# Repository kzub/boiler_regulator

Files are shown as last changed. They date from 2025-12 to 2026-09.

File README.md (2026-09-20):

# Arduino ESBE VRG131 Valve  Motor Controller

A custom firmware implementation for controlling stepper motors using an **Arduino Uno** and **CNC Shield V3**

## 🔧 Hardware Setup

* **Controller:** Arduino Uno + CNC Shield V3.
* **Drivers:** A4988 / DRV8825 (verified with active-low logic).
* **Motors:** NEMA 17 Stepper Motors.
* **Interface:** Rotary Encoder (KY-040 type) with Push Button.
* **Power:** 12V/24V external power supply for shield.

## 🚀 Key Features

* **Independent A-Axis:** Configured the 'A' slot on the CNC shield as an independent axis (Pins 12/13) by removing hardware clone jumpers.
* **Smart Power Management:** Implements "Auto-Enable" logic; drivers hold torque only during movement or menu interaction, and disable (idle) to reduce heat when inactive.
* **Debounced Interface:**
* **Hardware:** None
* **Software:** Non-blocking `millis()` based debounce logic for the button and Interrupt-based handling for the encoder.

## 🛠 Configuration Notes

* **Jumper Settings:** Remove **EN/GND** jumper cap from shield to allow software control of motor enable. Remove **X/Y/Z Clone** jumpers to isolate the A-axis.
* **Jumper Settings:** Install **A12** jumpers to control A axis
* **Pinout:**
* **Z-Axis:** Step (4), Dir (7)
* **A-Axis:** Step (12), Dir (13)
* **Global Enable:** Pin 8 (Active LOW)
* **Encoder:** Pin A2 & A3
* **Button:** Pin A1
* **Endsotps** Pins D11 and D9
* **Temperature sensors** Pin A0

## 📦 Dependencies (PlatformIO)

This project uses the following libraries:

* `waspinator/AccelStepper` (Motor control)
* `paulstoffregen/Encoder` (High-performance encoder reading)

---

### 📝 To-Do / Known Issues

* Ensure the driver Vref is calibrated to match motor current limits.
* If using Pin 12, ensure no SPI conflict if adding displays/SD cards later.
* **Counter constants are not travel:** `triggerBackoff()` normalises the counter to `BACKOFF_STEPS` at one end-stop and `MAX_POSITION_LIMIT - BACKOFF_STEPS` at the other, so the `9000` steps between those constants are a firmware convention and not the real valve travel (roughly `6000` steps). The webapp measures the travel during calibration instead of trusting that range; percentages built from the constants alone open a valve by about one and a half times the requested amount.
* **TODO — Motor 1 reversed endstops:** `motor1.setPinsInverted(true, false, false)` reverses the physical direction, but `manageMotors()` still associates negative motion with `PIN_COMMON_MIN` and positive motion with `PIN_COMMON_MAX`. On the installed controller Motor 1 therefore normalises `min` near `9500` and `max` near `500`, and intermediate travel leaves that range. The webapp handles this by anchoring on whichever constant it last saw, so it needs no separate switch; after fixing the firmware, just recalibrate.

---

### ⚙️ 3D Models (FreeCAD) to print CASE and mount parts included
#### All parts together

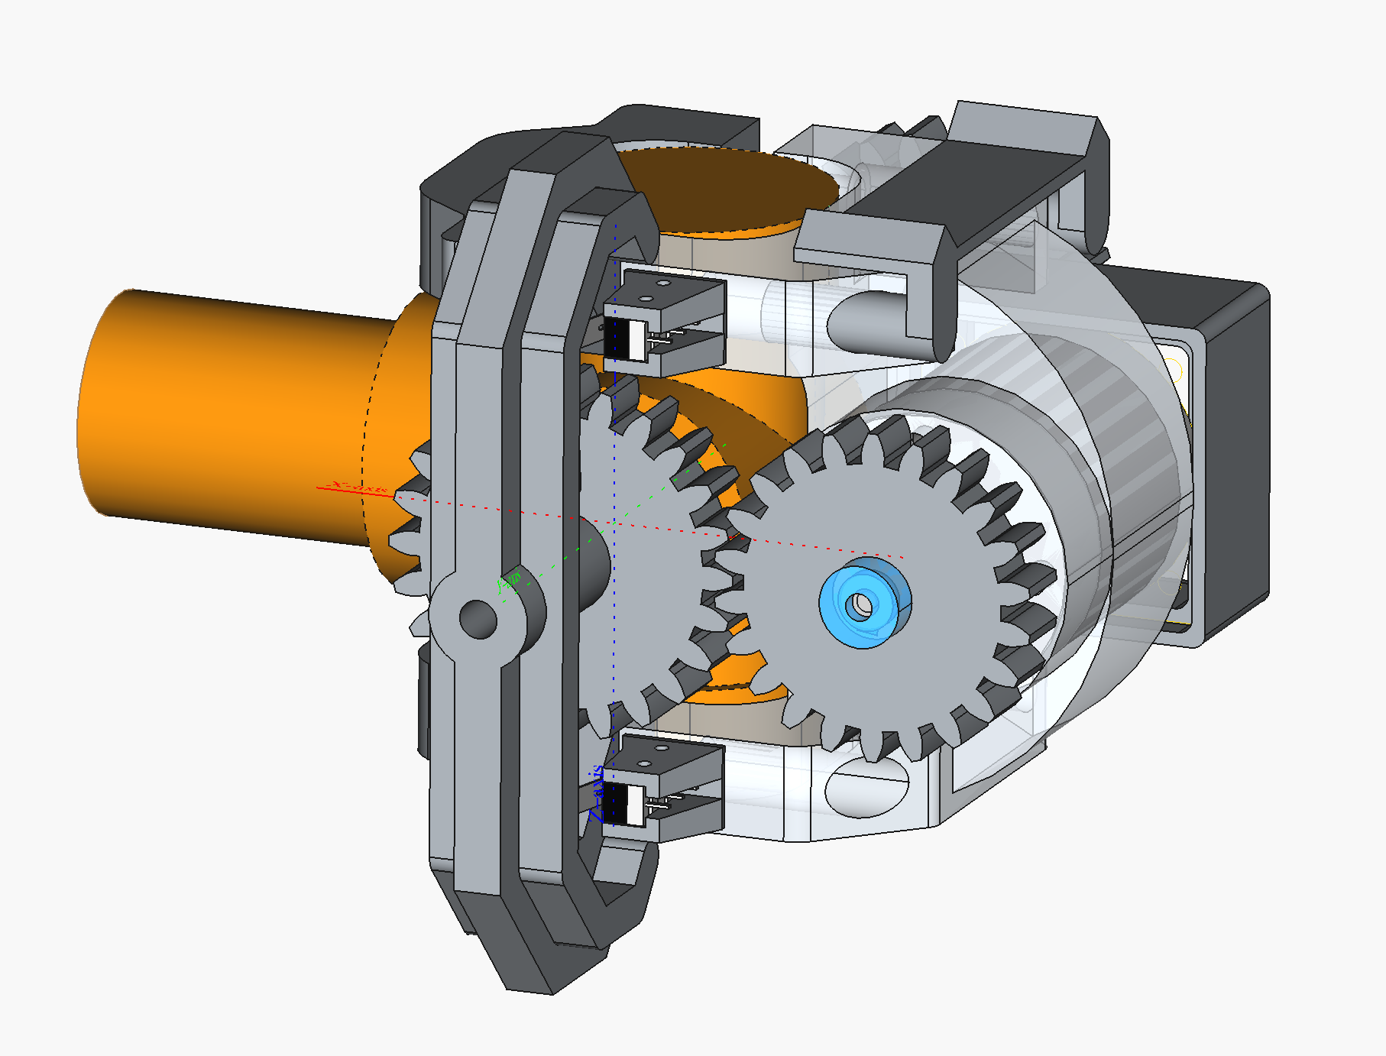
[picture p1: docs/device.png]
Device
 

#### Case

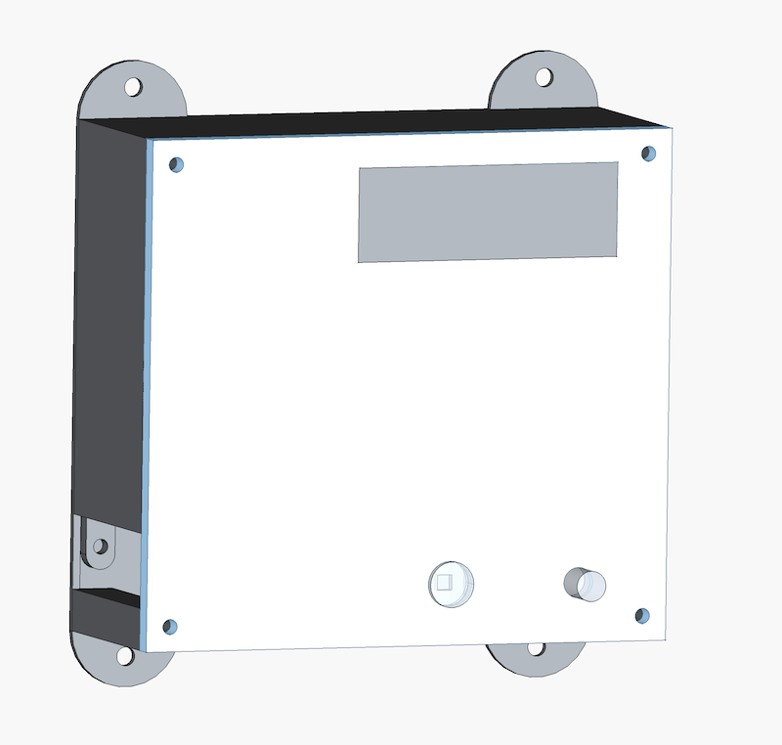
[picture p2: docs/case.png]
Case
 

 #### Real photo
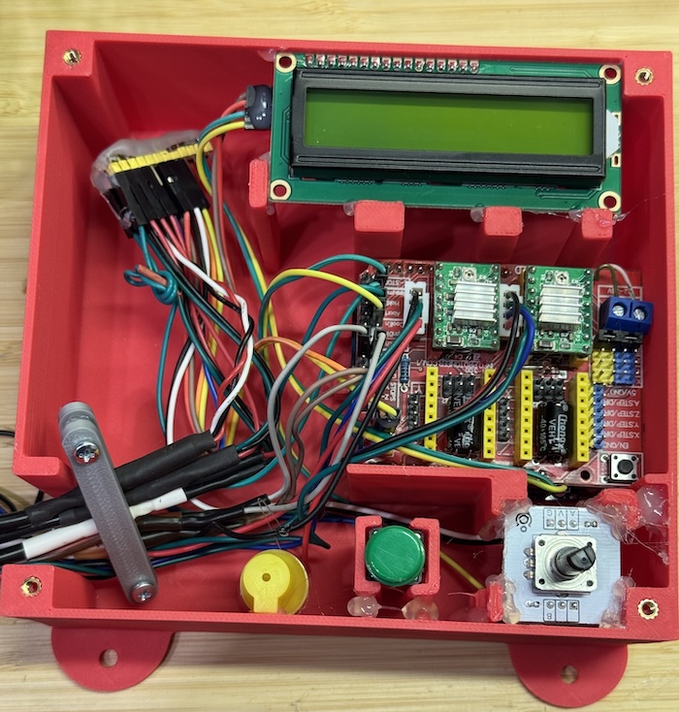
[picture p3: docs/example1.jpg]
 
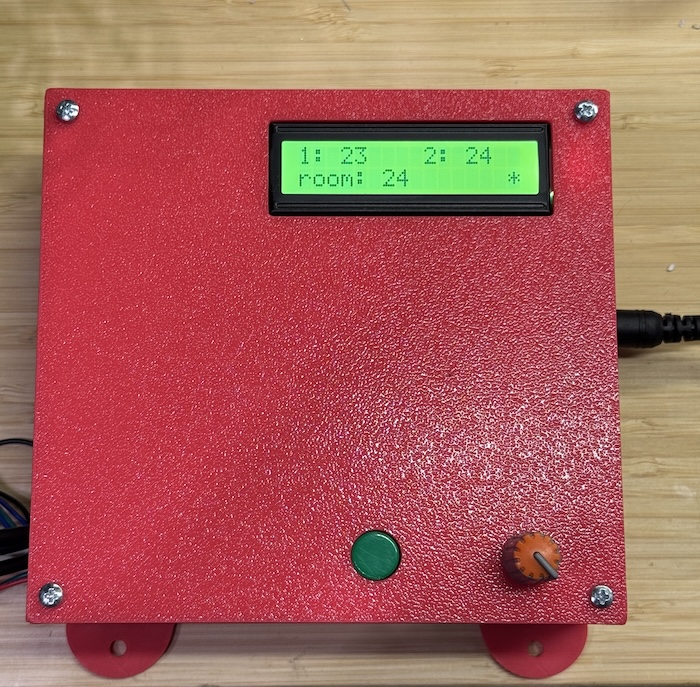
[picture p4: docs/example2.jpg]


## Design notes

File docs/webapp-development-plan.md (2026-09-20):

# План разработки Docker web-приложения для Boiler Regulator

Статус: **готов для передачи другой модели; выбран дизайн A «Домашняя панель»**.
Тема по умолчанию — auto, если владелец не задаст другую.

## 1. Цель

Создать мобильное web-приложение, запускаемое одним Docker Compose сервисом в
домашней сети. Приложение получает состояние Arduino Leonardo ETH, показывает
четыре температуры, калибрует логическую шкалу клапанов и позволяет отправить
первый или второй клапан к физическому пределу `MIN`/`MAX` либо установить
произвольное открытие от 0 до 100%.

Первый релиз должен быть простым, надёжным и безопасным от случайных повторных
команд. После перезапуска Arduino прежняя абсолютная шкала считается
недействительной и backend заново выполняет калибровку. История температур,
расписания, автоматическое регулирование и удалённый доступ через интернет не
входят в MVP.

## 2. Что уже есть в прошивке

Источник: `controller/src/main.cpp`.

### 2.1 Чтение состояния

`GET http://<controller-ip>/status`

Текущий ответ:

```json
{
  "fl1": 21.5,
  "fl2": 22.0,
  "boiler": 24.5,
  "room": 61.0,
  "m1": 100,
  "m2": 9900
}
```

Рабочее отображение для MVP, которое нужно подтвердить на реальном устройстве:

| Поле Arduino | Подпись в приложении |
| --- | --- |
| `fl1` | Первый этаж |
| `fl2` | Второй этаж |
| `boiler` | Температура воды котла |
| `room` | Бойлерная комната |
| `m1` | Позиция регулятора первого этажа |
| `m2` | Позиция регулятора второго этажа |

Не переименовывать поля прошивки в рамках первой версии web-приложения без
отдельного решения: flash ATmega32U4 почти заполнен. Человеческие имена следует
назначить на сервере web-приложения.

### 2.2 Управление

```text
GET /set?motor=1&pos=min
GET /set?motor=1&pos=max
GET /set?motor=2&pos=min
GET /set?motor=2&pos=max
```

Успешный ответ прошивки: `{"status":"ok"}`. Команда означает начало движения,
а не подтверждение достижения концевика. Прошивка также поддерживает
относительное движение. Backend использует его внутри для установки процента,
но не публикует клиенту сырые шаги.

### 2.3 Ограничения текущего API

- нет CORS, поэтому прямые запросы из страницы другого origin ненадёжны;
- все ответы имеют HTTP 200, включая ошибки разбора;
- нет версии API, метки времени, состояния online/busy/moving или результата
  достижения концевика;
- позиция мотора живёт в RAM и после перезапуска контроллера не обязательно
  отражает физическое положение до срабатывания концевика;
- температура читается по индексу OneWire; физическая привязка датчиков не
  закреплена ROM-адресами;
- специальное значение DS18B20 `-127°C` и другие невозможные значения API не
  маркирует как ошибку;
- команды изменения реализованы через GET и не имеют аутентификации;
- при занятости обоих моторов прошивка фактически обслуживает движение первого,
  затем второго, потому что в `manageMotors()` используется `else if`.

Эти ограничения должны быть обработаны прокси и UI, а не скрыты.

### 2.4 Важное свойство текущей шкалы

При достижении концевика прошивка сама переназначает логическую позицию:

- после `MIN` — `BACKOFF_STEPS`, сейчас это `100`;
- после `MAX` — `MAX_POSITION_LIMIT - BACKOFF_STEPS`, сейчас это `9900`.

То есть backend не измеряет реальное число физических шагов между концевиками:
прошивка нормализует счётчик в известный логический диапазон. Калибровка backend
на практике является homing-процедурой: довести клапан до обоих концевиков,
прочитать подтверждённые логические границы и только после этого разрешить
процентное управление. Нельзя hardcode `100/9900`: читать фактические значения
после каждого конца нужно для проверки успешности и совместимости с будущими
версиями прошивки.

### 2.5 Решение для MVP без изменения прошивки

MVP не меняет Arduino firmware. Backend ориентируется только на `m1` и `m2` из
существующего `/status`:

- изменение позиции между poll-запросами означает, что логический счётчик мотора
  движется;
- несколько одинаковых значений подряд после команды означают предполагаемое
  окончание движения;
- значение вне откалиброванного диапазона, прежде всего `0` после reset Arduino,
  инвалидирует шкалу и запускает повторную калибровку;
- изменение позиции без активной backend-команды считается локальным/внешним
  управлением. Если значение остаётся внутри шкалы, backend принимает новую
  позицию и пересчитывает процент.

Backend хранит `lastObservedRaw` и ожидаемую цель. Расхождение с целью само по
себе не всегда означает потерю калибровки: штатный энкодер контроллера также
может изменить позицию. Причиной invalidation являются выход за границы шкалы,
характерный reset в `0`, невозможный скачок или неуспех контрольного движения.

Критическое аппаратное ограничение: `currentPosition()` — программный счётчик
отправленных шагов, а не датчик положения вала. Если физически провернуть вал или
клапан руками без шагов от Arduino, `m1/m2` не изменятся и backend не сможет это
обнаружить. Под «покрутить руками» в поддерживаемом сценарии понимается вращение
штатного энкодера UI, которое запускает мотор и меняет счётчик. Для обнаружения
чисто механического смещения понадобился бы отдельный датчик положения либо
периодическая/ручная повторная homing-калибровка.

## 3. Предлагаемая архитектура

```mermaid
flowchart LR
    P[Мобильный браузер / PWA] -->|HTTPS или HTTP в LAN| W[Docker web service]
    W -->|/api/*| B[Backend proxy]
    B -->|HTTP, короткий timeout| A[Arduino Leonardo ETH]
    B --> C[Calibration manager + command queue]
    C --> D[(Persisted state /data)]
    W --> S[Статические frontend-файлы]
```

### 3.1 Почему нужен backend proxy

Прокси находится в том же origin, что и страница, и решает сразу несколько
задач: обходит отсутствие CORS на Arduino, скрывает адрес устройства от
frontend-кода, нормализует ошибки, вводит timeout, валидирует команды и даёт
возможность позднее добавить авторизацию без изменения прошивки.

Backend также является единственным владельцем очереди движения и состояния
калибровки. Browser polling не должен сам определять границы, вычислять шаги или
отправлять сырой relative move.

### 3.2 Рекомендуемый стек

Для реализации рекомендуется:

- frontend: React + TypeScript + Vite;
- стили: обычный CSS с небольшим набором design tokens, без тяжёлого UI-kit;
- backend: Node.js + TypeScript + Fastify либо минимальный HTTP server;
- runtime: один production-контейнер, который обслуживает собранную статику и
  `/api`; multi-stage Docker build;
- тесты: Vitest для unit/component, Testing Library для UI, Playwright для одного
  критического mobile flow;
- форматирование/проверки: ESLint + TypeScript strict mode.

Допустимая более компактная альтернатива — Preact вместо React. Другой модели не
следует менять стек без причины: важнее простой единый контейнер и предсказуемая
поддержка, чем минимальный размер bundle любой ценой.

### 3.3 Предлагаемая структура папки `webapp`

```text
webapp/
├── src/
│   ├── client/
│   │   ├── api/
│   │   ├── components/
│   │   ├── hooks/
│   │   ├── styles/
│   │   ├── App.tsx
│   │   └── main.tsx
│   ├── server/
│   │   ├── arduino-client.ts
│   │   ├── calibration-manager.ts
│   │   ├── calibration-store.ts
│   │   ├── command-queue.ts
│   │   ├── config.ts
│   │   ├── routes.ts
│   │   └── server.ts
│   └── shared/
│       └── contracts.ts
├── tests/
│   ├── unit/
│   ├── component/
│   └── e2e/
├── public/
├── .dockerignore
├── .env.example
├── Dockerfile
├── compose.yaml
├── package.json
├── tsconfig.json
└── README.md
```

Не создавать отдельные frontend/backend контейнеры для MVP: это усложнит
развёртывание без практической пользы.

### 3.4 Хранение состояния калибровки

Хранить небольшой versioned JSON в `/data/calibration.json`, записывая его
атомарно через временный файл и rename. Для двух регуляторов база данных не
нужна. `/data` должен быть Docker volume, иначе перезапуск web-контейнера будет
запускать лишнюю полную калибровку.

Минимальная persisted schema:

```json
{
  "schemaVersion": 1,
  "regulators": {
    "1": {
      "minRaw": 100,
      "maxRaw": 9900,
      "lastObservedRaw": 4510,
      "lastDesiredPercent": 45,
      "calibratedAt": "2026-09-13T10:00:00.000Z"
    },
    "2": {
      "minRaw": 100,
      "maxRaw": 9900,
      "lastObservedRaw": 5980,
      "lastDesiredPercent": 60,
      "calibratedAt": "2026-09-13T10:02:00.000Z"
    }
  }
}
```

`lastDesiredPercent` не является доказательством текущего физического положения.
Он нужен только как возможная цель восстановления после новой калибровки, если
владелец выберет такой режим. Текущий процент всегда вычисляется из свежего raw
position контроллера. `lastObservedRaw` нужен для определения расхождений при
следующем poll/start, но не заменяет физический датчик положения.

Не перезаписывать файл на каждом poll. Обновлять persisted `lastObservedRaw`
после стабилизации движения, завершения внешнего изменения или с debounce;
калибровочные границы записывать только после полной успешной калибровки.

## 4. Внутренний API Docker-приложения

Браузер работает только с этим API. Адрес Arduino не передаётся клиенту.

### 4.1 `GET /api/status`

Нормализованный успешный ответ:

```json
{
  "temperatures": {
    "floor1": 21.5,
    "floor2": 22.0,
    "boilerWater": 24.5,
    "boilerRoom": 61.0
  },
  "regulators": {
    "floor1": {
      "position": 4216,
      "percent": 42,
      "targetPercent": null,
      "state": "ready"
    },
    "floor2": {
      "position": 9900,
      "percent": 100,
      "targetPercent": null,
      "state": "ready"
    }
  },
  "controller": { "online": true },
  "calibration": { "state": "ready", "progressPercent": 100 },
  "receivedAt": "2026-09-13T10:30:00.000Z"
}
```

Правила proxy:

- timeout запроса к Arduino: начать с 2000 ms, вынести в env;
- проверять `Content-Type` снисходительно, так как прошивка минималистична, но
  строго проверять JSON и наличие нужных числовых полей;
- значения `-127`, `85` при старте датчика, `NaN`, infinity и заведомо выходящие
  за разумный диапазон не показывать как валидную температуру; возвращать `null`
  и диагностический массив `warnings`;
- при недоступности Arduino возвращать `503` с коротким стабильным кодом ошибки,
  не раскрывая stack trace;
- `receivedAt` создаётся proxy только после успешного ответа устройства;
- при позиции вне сохранённой шкалы немедленно вернуть `percent: null` и
  поставить автоматическую калибровку в очередь;
- если после старта оба счётчика равны `0`, считать это reset Arduino и
  инвалидировать обе шкалы;
- если только один счётчик равен `0`/вышел из диапазона, инвалидировать обе шкалы:
  концевики общие, а полная последовательная калибровка дешевле и понятнее
  частично доверенного состояния;
- не кешировать HTTP-ответ браузера (`Cache-Control: no-store`).

### 4.2 `POST /api/regulators/:id/limit`

Тело запроса:

```json
{ "limit": "min" }
```

Где `:id` — только `1` или `2`, `limit` — только `min` или `max`. Backend
преобразует валидный запрос в существующий Arduino GET endpoint. Любые другие
значения отклоняются с `400` и не отправляются устройству.

Успешный ответ Docker API должен быть `202 Accepted`, потому что Arduino
подтверждает приём, но не завершение движения:

```json
{
  "accepted": true,
  "regulator": 1,
  "target": "min",
  "acceptedAt": "2026-09-13T10:31:00.000Z"
}
```

Правила управления:

- backend не повторяет управляющий запрос автоматически: retry может привести к
  нежелательной повторной команде;
- одновременно допускается только один выполняющийся HTTP-запрос команды;
- на уровне UI кнопка блокируется сразу после нажатия и до ответа;
- после `202` UI показывает «Команда принята», а не «Клапан установлен»;
- отсутствие в текущей прошивке признака окончания движения нужно честно
  отразить в UI; нельзя имитировать подтверждённый успех таймером;
- proxy логирует только тип команды, номер регулятора, время, результат и
  длительность; не логирует секреты или полные заголовки.

### 4.3 `POST /api/regulators/:id/target`

Тело запроса:

```json
{ "percent": 55 }
```

Требования:

- `percent` — конечное число от 0 до 100 включительно; UI предлагает шаг 5%, но
  API принимает любое целое значение;
- endpoint доступен только в состоянии calibration `ready`, когда обе свежие
  позиции находятся внутри сохранённых шкал;
- backend вычисляет `targetRaw = round(minRaw + percent / 100 *
  (maxRaw - minRaw))`;
- затем читает свежий `currentRaw`, вычисляет `delta = targetRaw - currentRaw` и
  отправляет Arduino существующий relative command `pos=+N` или `pos=-N`;
- если `delta == 0`, команда мотору не отправляется, API отвечает текущим
  состоянием;
- raw target всегда clamp в `[minRaw, maxRaw]`;
- до завершения движения новые команды этому и второму мотору либо отклоняются
  `409 CONTROLLER_BUSY`, либо помещаются в одну явно реализованную очередь. Для
  MVP рекомендуется одна очередь и не более одной pending user command;
- после приёма backend сохраняет `lastDesiredPercent`, но UI различает requested,
  moving и достигнутую по данным позицию;
- по окончании движения проверить, что фактическая позиция находится в заданном
  допуске, например ±1% шкалы. Иначе вернуть/зафиксировать motion error и не
  показывать цель как достигнутую.

Формула обратного преобразования:

```text
percent = clamp(round((currentRaw - minRaw) * 100 / (maxRaw - minRaw)), 0, 100)
```

Деление запрещено, если шкала отсутствует или `maxRaw <= minRaw`.

### 4.4 Calibration API

- `POST /api/calibration` — вручную запустить/повторить полную калибровку;
- `GET /api/calibration` — состояние и прогресс для UI;
- повторный POST во время calibration возвращает `409 CALIBRATION_IN_PROGRESS`;
- manual limit/target commands во время calibration возвращают
  `409 CALIBRATION_IN_PROGRESS`.

Пример состояния:

```json
{
  "state": "running",
  "phase": "motor1_max",
  "progressPercent": 38,
  "startedAt": "2026-09-13T10:00:00.000Z",
  "error": null
}
```

### 4.5 State machine калибровки

Состояния:

```text
uncalibrated
  → motor1_min → motor1_max
  → motor2_min → motor2_max
  → restoring (если выбран режим восстановления)
  → ready

любой рабочий этап → failed
позиция вне шкалы/reset в 0 → uncalibrated → новая calibration
```

Алгоритм каждого этапа:

1. Получить глобальную блокировку движения.
2. Прочитать стартовую позицию и запомнить время/значение наблюдения.
3. Отправить ровно одну limit-команду без retry.
4. Poll status каждые 250–500 ms. После первого изменения считать мотор
   движущимся. Считать этап завершённым после не менее чем 4–6 одинаковых
   значений подряд и общего стабильного интервала не менее 1.5 s.
5. Если начальное и конечное значения совпали (например, клапан уже был у
   концевика), не завершать этап мгновенно: выдержать минимальное окно наблюдения
   2 s и проверить ожидаемую границу/результат следующей фазы.
6. Ограничить этап timeout примерно 30 s: safety move в прошивке составляет до
   20000 шагов при скорости 1000 шагов/с плюс backoff.
7. Прочитать финальную raw position. Для `MIN` сохранить `minRaw`, для `MAX` —
   `maxRaw`.
8. После пары проверить `maxRaw > minRaw` и разумный минимальный span. Не
   продолжать с нулевой или инвертированной шкалой.
9. После успешной калибровки обоих моторов записать единый snapshot атомарно.

Не записывать частично откалиброванную шкалу как `ready`. Калибровка выполняется
строго последовательно из-за общих концевиков. Stability detection не доказывает
механическое движение: оно доказывает только завершение изменения программного
счётчика. Поэтому timeout, проверка конечных границ и возможность ручной
повторной калибровки обязательны.

### 4.6 Поведение при старте и потере питания

При старте backend:

1. Загрузить persisted snapshot.
2. Получить status Arduino.
3. Если snapshot валиден и обе текущие позиции находятся внутри соответствующих
   шкал — принять их как свежие, пересчитать проценты и перейти в `ready` без
   движения.
4. Если snapshot отсутствует/повреждён, позиция равна `0` или находится вне
   шкалы — удалить обе шкалы из памяти, записать `uncalibrated` и запустить
   автоматическую калибровку.
5. Если Arduino недоступен — оставаться `waiting_for_controller`; начать
   calibration после восстановления связи.

При потере связи во время работы не считать это немедленным доказательством
reset. Отключить команды, сохранить последнюю информацию только как stale и
ждать возвращения. После возврата сравнить raw positions со шкалой и последним
наблюдением. Значение `0`/вне диапазона запускает recalibration; новое значение
внутри диапазона принимается как локальное управление и становится текущим.

Эвристика не может доказать каждый reboot. Если контроллер успел перезапуститься,
а затем его штатным энкодером довели до значения внутри старой шкалы до первого
backend poll, reset может остаться незамеченным. Это принятый риск варианта без
изменения firmware; он должен быть указан в README и компенсирован доступной
ручной кнопкой «Перекалибровать».

### 4.7 Матрица расхождений позиции

| Наблюдение | Интерпретация | Действие backend |
| --- | --- | --- |
| Позиция меняется после backend-команды | Мотор движется | Продолжать частый poll, показывать moving |
| Позиция стабильна не менее 1.5 s | Предполагаемая остановка | Сверить с target/limit и снять moving |
| Позиция изменилась без backend-команды, но внутри шкалы | Управление штатным энкодером или другим API-клиентом | Принять raw, пересчитать процент, сбросить устаревший draft target |
| Позиция стабильна внутри шкалы, но не совпала с backend target | Команда не достигла ожидаемой логической цели | Показать warning; не выдавать цель за достигнутую |
| Одна или обе позиции равны `0` после прежней валидной шкалы | Наиболее вероятен reset Arduino | Инвалидировать обе шкалы и запустить calibration |
| Позиция ниже `minRaw` или выше `maxRaw` с допуском | Счётчик/шкала больше не согласованы | Инвалидировать обе шкалы и запустить calibration |
| Arduino не отвечает | Сетевая проблема или отключение питания, причина неизвестна | Показать offline, пока не инвалидировать; проверить позиции после возврата |
| Вал повернули физически, но raw не изменился | Не наблюдается существующим оборудованием | Backend ничего определить не может; нужна ручная calibration |

### 4.8 Служебные endpoints

- `GET /health/live` — процесс запущен, без обращения к Arduino;
- `GET /health/ready` — конфигурация валидна; допустимо возвращать ready даже при
  временно выключенном Arduino, чтобы Docker не перезапускал приложение из-за
  сетевой проблемы устройства.

## 5. Конфигурация и Docker

Минимальные переменные окружения:

```dotenv
CONTROLLER_BASE_URL=http://192.168.88.20
CONTROLLER_TIMEOUT_MS=2000
PORT=8080
STATUS_POLL_INTERVAL_MS=5000
MOTION_POLL_INTERVAL_MS=300
MOTION_TIMEOUT_MS=30000
AUTO_CALIBRATE=true
CALIBRATION_DATA_PATH=/data/calibration.json
```

Требования:

- `CONTROLLER_BASE_URL` обязателен и валидируется при старте;
- URL разрешает только `http:`/`https:`, query и credentials запрещены;
- production image запускается не от root;
- зависимости устанавливаются lockfile-режимом;
- build stage не попадает в runtime image;
- контейнер имеет healthcheck по `/health/live`;
- `compose.yaml` содержит `restart: unless-stopped`, проброс `${WEB_PORT:-8080}:8080`
  и named volume для `/data`;
- адрес Arduino задаётся env, а не hardcode;
- README содержит команды запуска, обновления, просмотра состояния и остановки;
- если приложение будет доступно только в LAN, не заявлять HTTPS. Для удалённого
  доступа нужен отдельный reverse proxy/VPN и решение по авторизации.

## 6. Поведение мобильного интерфейса

### 6.1 Загрузка и обновление

- при открытии сразу запросить `/api/status`;
- затем опрашивать раз в 5 секунд; интервал приходит из build config или остаётся
  фиксированным в клиенте, серверный env не должен случайно обещать клиенту то,
  чего он не использует;
- не запускать новый poll, пока предыдущий не завершён;
- при уходе вкладки в background снизить частоту или остановить polling, при
  возврате обновить сразу;
- показывать «Обновлено N сек. назад»;
- после двух последовательных ошибок показывать заметный offline state и время
  последних достоверных данных;
- при ошибке не обнулять экран и не выдавать старые данные за свежие.

### 6.2 Температуры

- показывать одну цифру после запятой и `°C`;
- для `null` показывать `—` и подпись «нет данных»;
- не окрашивать температуру как «нормальную/опасную» без согласованных порогов;
- подписи должны однозначно различать «Температура воды котла» и «Бойлерная
  комната»;
- числа использовать с tabular figures, чтобы обновление не дёргало layout.

### 6.3 Карточка регулятора и процентное управление

- выбран layout A: две карточки этажей одновременно видны под инженерными
  температурами;
- в `ready` крупно показывать текущий процент, рядом вторично — raw position;
- `−5%`/`+5%` и ползунок меняют локальный draft target, не отправляя движение;
- отдельная кнопка «Установить N%» открывает подтверждение и создаёт ровно одну
  backend-команду;
- ползунок имеет шаг 1%, кнопки — шаг 5%;
- различать `Текущее 42%` и `Цель 55%`, особенно во время движения;
- при `percent: null` не показывать 0%; вместо этого выводить «Шкала не
  откалибрована»;
- во время calibration показывать текущую фазу понятным текстом, общий progress
  и предупреждение, что оба регулятора будут двигаться автоматически;
- при `failed` показать причину и кнопку «Повторить калибровку»;
- управление обеими карточками блокируется во время глобальной калибровки.
- если позиция меняется без команды web-приложения, плавно обновить текущий
  процент и пометить событие как локальное управление без тревожного сообщения;

### 6.4 Команды MIN/MAX

- в каждом блоке явно указать этаж;
- зона нажатия не менее 44 px, расстояние между конфликтующими кнопками;
- подтверждение должно назвать этаж и направление: «Первый этаж → MAX?»;
- пока запрос отправляется, обе кнопки этого регулятора отключены;
- защита от double tap обязательна;
- после ответа показать неблокирующее сообщение «Команда принята»;
- при timeout показать «Не удалось подтвердить приём команды». Не предлагать
  автоматический retry; пользователь может сначала проверить состояние;
- позицию (`m1`/`m2`) показывать как вторичную диагностическую информацию и не
  превращать в проценты, пока текущая позиция не подтверждена откалиброванным
  диапазоном.

### 6.5 Accessibility и mobile details

- корректный viewport и отсутствие горизонтальной прокрутки при 320 px;
- поддержка safe-area inset на iPhone;
- системный шрифт и размер основного текста не меньше 16 px;
- видимый keyboard focus;
- semantic headings/buttons/dialog;
- `aria-live` для статуса обновления и результата команды;
- `prefers-reduced-motion` отключает декоративные переходы;
- светлая и тёмная тема должны иметь достаточный контраст, если выбран режим
  auto.

## 7. Обработка ошибок

Нужны стабильные коды, которые frontend переводит в русские сообщения:

| HTTP | Код | Смысл для UI |
| --- | --- | --- |
| 400 | `INVALID_REQUEST` | Внутренняя ошибка запроса; команда не отправлена |
| 409 | `CONTROLLER_BUSY` | Дождитесь завершения текущего движения |
| 409 | `CALIBRATION_REQUIRED` | Процент недоступен до калибровки |
| 409 | `CALIBRATION_IN_PROGRESS` | Идёт автоматическая калибровка |
| 502 | `INVALID_CONTROLLER_RESPONSE` | Контроллер ответил неожиданно |
| 502 | `CALIBRATION_FAILED` | Концевик/шкала не подтверждены |
| 503 | `CONTROLLER_UNREACHABLE` | Контроллер недоступен |
| 504 | `CONTROLLER_TIMEOUT` | Контроллер не ответил вовремя |

Логи сервера должны позволять отличить DNS/connect/timeout/invalid JSON, но API
не должен возвращать внутренние адреса и stack traces пользователю.

## 8. Тестовая стратегия

Для разработки создать mock Arduino server с тем же минимальным контрактом. Это
позволит другой модели и CI работать без физического контроллера.

Обязательные unit-тесты:

- преобразование Arduino status в публичный контракт;
- валидация четырёх температур и двух позиций;
- позиция `0`/вне диапазона немедленно инвалидирует обе шкалы;
- повторный backend start с позициями внутри шкал не запускает движения;
- первый start без snapshot запускает calibration;
- внешнее изменение внутри шкалы обновляет процент без recalibration;
- изменение позиции определяется по последовательности status samples;
- окончание движения определяется только после заданного stable window;
- state machine проходит четыре limit-фазы строго последовательно;
- timeout/ошибка любой фазы не сохраняет частичную шкалу как ready;
- валидация `minRaw < maxRaw` и минимального span;
- формулы raw↔percent, clamp, rounding и границы 0/100%;
- атомарная запись и восстановление calibration JSON;
- target percent преобразуется ровно в одну relative Arduino command;
- маппинг регулятора и `min/max` в Arduino URL;
- timeout, invalid JSON, отсутствующее поле, сетевой отказ;
- запрет неизвестного motor/limit;
- отсутствие автоматического retry управляющей команды.

Обязательные component/UI-тесты:

- initial loading → актуальные данные;
- offline state сохраняет последние значения и помечает их устаревшими;
- `null` температура отображается как «нет данных»;
- подтверждение содержит правильный этаж и предел;
- draft target меняется кнопками/ползунком без сетевой команды;
- нажатие «Установить» отправляет ровно один target request;
- uncalibrated state скрывает процент и блокирует target controls;
- calibration progress и failed state отображаются корректно;
- double tap не создаёт две команды;
- success означает «принята», а не «выполнена»;
- все интерактивные элементы доступны с клавиатуры.

Минимальный Playwright mobile smoke test (например, viewport iPhone 13): открыть
экран после calibration, увидеть четыре температуры и два процента, подготовить
цель 55% для регулятора 1, подтвердить одну команду, дождаться ready state, затем
смоделировать сброс обеих позиций в `0` и увидеть блокировку UI с новой
calibration.

Ручная проверка на реальном устройстве:

1. Сверить каждый из четырёх датчиков с физическим расположением.
2. Выполнить `MIN` и `MAX` для каждого клапана по отдельности.
3. Проверить отображение позиции до, во время и после движения.
4. Проверить цели 5%, 50% и 95% для каждого клапана.
5. Отключить Ethernet Arduino и проверить offline UI без ложной invalidation.
6. Перезапустить Arduino, проверить сброс `m1/m2` в `0`, немедленный сброс
   процентов и автоматическую повторную калибровку.
7. Перезапустить только Docker-контейнер при работающем Arduino и убедиться, что
   persisted шкала используется без движения, если позиции внутри диапазона.
8. Повернуть штатный энкодер контроллера и проверить обновление процента без
   повторной калибровки.
9. Проверить телефон шириной 320–430 px, portrait, светлую и тёмную системную
   тему.

## 9. Этапы разработки и checklist

### Этап 0 — зафиксировать решения

- [x] Владелец выбрал вариант дизайна A «Домашняя панель».
- [ ] Зафиксирована тема: light/dark/auto.
- [ ] На физическом устройстве подтверждён mapping четырёх датчиков.
- [ ] Подтверждено значение `MIN`/`MAX` для каждого клапана; до этого UI не
      использует слова «открыть/закрыть».
- [ ] Подтверждено, что приложение остаётся только в доверенной LAN, либо создана
      отдельная задача на authentication/TLS.
- [ ] Выбрано положение после автокалибровки: предыдущая цель, `MIN` или `MAX`.

### Этап 1 — проверить поведение существующей firmware

- [ ] Не изменять `controller/src/main.cpp`.
- [ ] Замерить изменение `m1/m2` во время движения с poll 250/300/500 ms.
- [ ] Подтвердить, что `/status` отвечает во время обычного движения мотора.
- [ ] Замерить время, после которого позиция стабилизируется у обоих концевиков.
- [ ] Подтвердить реальные финальные позиции после `MIN` и `MAX` для каждого
      мотора.
- [ ] Выполнить reset/power cycle и подтвердить, что оба счётчика становятся `0`.
- [ ] Повернуть штатный энкодер и подтвердить, что соответствующее `m1/m2`
      изменяется.
- [ ] Отдельно зафиксировать, что физический поворот вала без работы мотора не
      отражается в `/status`.

Критерий завершения: измерены poll/stability параметры и подтверждены наблюдаемые
признаки движения/reset, на которых будет основан backend.

### Этап 2 — scaffold и контракты

- [ ] Создать frontend/server TypeScript project внутри `webapp`.
- [ ] Добавить lockfile, strict TypeScript, lint, test и build scripts.
- [ ] Описать shared types публичного API.
- [ ] Добавить `.env.example`, не коммитить реальный секретный env.
- [ ] Создать mock Arduino server и фикстуры good/invalid/offline.
- [ ] Mock должен симулировать изменение/стабилизацию позиции, reset в `0`,
      локальное управление, концевики и calibration failure.
- [ ] Обновить `webapp/README.md` точными командами разработки.

Критерий завершения: чистая установка зависимостей, lint, typecheck и пустой
production build выполняются одной документированной последовательностью.

### Этап 3 — backend proxy и calibration manager

- [ ] Реализовать и протестировать config validation.
- [ ] Реализовать Arduino client с `AbortSignal.timeout` или эквивалентом.
- [ ] Реализовать `GET /api/status` и нормализацию ответа.
- [ ] Реализовать `POST /api/regulators/:id/limit` со строгой validation.
- [ ] Реализовать persisted versioned calibration store в `/data` с atomic write.
- [ ] Реализовать глобальную command queue/lock.
- [ ] Реализовать полную последовательную state machine калибровки.
- [ ] Реализовать comparison с persisted bounds/last observed position и
      invalidation при `0`/выходе из диапазона.
- [ ] Реализовать automatic calibration после первого запуска/reset heuristic.
- [ ] Реализовать `GET/POST /api/calibration`.
- [ ] Реализовать raw↔percent и `POST /api/regulators/:id/target`.
- [ ] Реализовать motion detection по изменению raw position.
- [ ] Реализовать completion по stable sample window, target tolerance и timeout.
- [ ] Реализовать обработку локального движения внутри шкалы без invalidation.
- [ ] Убедиться, что command request не имеет retry.
- [ ] Добавить `/health/live` и `/health/ready`.
- [ ] Добавить structured logging без утечки внутренних деталей в API.
- [ ] Добавить graceful shutdown.

Критерий завершения: backend проходит unit/integration тесты против mock Arduino,
включая полный calibration flow, reset в `0`, внешнее движение, target 0–100%,
timeout и malformed JSON. Ни один failure path не оставляет ложное состояние
`ready`.

### Этап 4 — базовый mobile UI

- [ ] Реализовать выбранную компоновку A «Домашняя панель».
- [ ] Создать компоненты TemperatureMetric, RegulatorControl, ConnectionStatus,
      CommandConfirm и Toast/InlineNotice.
- [ ] Реализовать initial load, polling без пересечений и visibility handling.
- [ ] Реализовать fresh/stale/offline states.
- [ ] Реализовать форматирование температур и missing sensor state.
- [ ] Показывать позицию только как диагностические шаги.
- [ ] Добавить current/draft/target percent, кнопки ±5%, slider и одну кнопку
      применения.
- [ ] Добавить calibration progress, uncalibrated и failed states.
- [ ] Реализовать подтверждение команды и блокировку double tap.
- [ ] Различить accepted, timeout и rejected сообщения.
- [ ] Проверить 320/360/390/430 px без горизонтального overflow.

Критерий завершения: все четыре температуры, текущие проценты, постепенная
установка и четыре limit-действия доступны на телефоне. UI никогда не вычисляет
процент из позиции вне шкалы и не заявляет о достижении цели без стабильных
данных контроллера.

### Этап 5 — дизайн, доступность и устойчивость

- [ ] Применить выбранные цвета, typography, spacing и состояния.
- [ ] Добавить auto theme, если она выбрана.
- [ ] Проверить контраст, focus, screen reader names и reduced motion.
- [ ] Добавить safe-area padding.
- [x] Добавить Error Boundary и понятный фатальный экран.
- [ ] Добавить component tests и mobile Playwright smoke test.
- [ ] Проверить отсутствие layout shift при обновлении чисел.
- [x] Ограничен retention диагностического журнала: backend хранит 500 последних
      записей (`defaultJournalLimit`), browser — 200 (`browserLogLimit`) в
      `sessionStorage` с уменьшением сохранённой копии при отказе quota;
      обрезание покрыто unit-тестами.

Критерий завершения: выбранный дизайн соответствует макету, основные сценарии
проходят мышью, touch и клавиатурой.

### Этап 6 — Docker и эксплуатационная документация

- [ ] Создать multi-stage Dockerfile и `.dockerignore`.
- [ ] Запустить runtime от non-root пользователя.
- [ ] Добавить `compose.yaml`, healthcheck и restart policy.
- [ ] Добавить named volume для `/data/calibration.json`.
- [ ] Проверить конфигурацию с IP реального Arduino.
- [ ] Проверить image на отсутствие devDependencies/build sources, где возможно.
- [ ] Документировать start/update/logs/stop/backup config.
- [ ] Добавить раздел troubleshooting: timeout, wrong IP, invalid sensor,
      controller reboot.

Критерий завершения: на чистой машине с Docker приложение запускается одной
командой и открывается с телефона в той же LAN.

### Этап 7 — приёмка на устройстве

- [ ] Выполнить ручной hardware checklist из раздела 8.
- [ ] Проверить минимум 30 минут polling без роста памяти и каскада запросов.
- [ ] Проверить восстановление после перезапуска web-контейнера.
- [ ] Проверить восстановление после потери/возврата Arduino в сети.
- [ ] Проверить защиту от повторного нажатия на реальном touch-устройстве.
- [ ] Проверить полный power-cycle Arduino с автоматической invalidation и
      calibration.
- [ ] Проверить, что restart только web-контейнера не двигает клапаны повторно.
- [ ] Зафиксировать фактический mapping датчиков в README.
- [ ] Зафиксировать URL приложения и параметры compose для домашнего сервера.

Критерий завершения MVP: приложение устойчиво показывает четыре корректно
подписанные температуры, откалиброванные проценты двух клапанов, принимает
только разрешённые limit/percent команды, сбрасывает шкалу при наблюдаемом reset
позиции, честно показывает состояние связи и разворачивается через Docker по
инструкции.

## 10. Опциональный этап после MVP

Не включать эти пункты в первую реализацию без отдельного запроса:

- PWA manifest, иконки и offline application shell;
- история температур и графики (потребуют хранилища);
- автоматический режим/расписание;
- push-уведомления;
- authentication и remote access;
- изменение IP Arduino из web UI;
- возможное будущее обновление прошивки для ROM-address датчиков, boot/session
  id, command id и подтверждённого результата достижения механической цели.

## 11. Правила для модели-исполнителя

1. Не изменять `controller/src/main.cpp` в рамках web MVP. План намеренно основан
   только на существующих `m1/m2`.
2. Если firmware станет отдельной задачей, соблюдать `AGENTS.md`: никаких Arduino
   `String`, статические строки через `F()`, никаких тяжёлых библиотек,
   обязательно `pio run` и отчёт по Flash/RAM.
3. Не угадывать физическую семантику датчиков и направления клапана; использовать
   подтверждённый mapping.
4. Не добавлять автоматический retry для управляющих команд.
5. Не сообщать пользователю «достигнут MIN/MAX», пока API не умеет это
   подтверждать.
6. Не публиковать порт приложения в интернет без отдельного security решения.
7. Делать каждый этап небольшим проверяемым изменением и отмечать checklist только
   после теста соответствующего критерия завершения.
8. Не утверждать, что backend обнаруживает физический ручной поворот вала: без
   датчика обратной связи это технически невозможно.

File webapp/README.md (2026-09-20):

# Boiler Regulator Web App

Mobile-first панель для контроллера клапанов. Выбран дизайн A «Домашняя панель»;
тема следует системной (auto). Приложение не меняет прошивку Arduino.

## Запуск в Docker

На домашнем сервере создайте `.env` из примера и укажите IP Arduino:

```sh
cp .env.example .env
# отредактируйте CONTROLLER_BASE_URL в .env
docker compose up -d --build
```

Панель будет доступна по `http://<адрес-сервера>:8080`. Она рассчитана только на
доверенную LAN. Не публикуйте этот порт в интернет без отдельного reverse proxy,
TLS и аутентификации.

Полезные команды:

```sh
docker compose logs -f
docker compose pull && docker compose up -d --build
docker compose down
```

Калибровка и последний наблюдавшийся процент открытия сохраняются в named volume
`calibration-data`; его не следует удалять при обычном обновлении. Для резервной
копии можно сохранить содержимое `/data/calibration.json` из контейнера. Если
Arduino перезапустится и вернёт `0` или позицию вне сохранённой шкалы, сервер
пометит шкалу недействительной. При следующей калибровке он измерит MIN/MAX и
вернёт оба регулятора к последним сохранённым процентам открытия. Автоматический
запуск этой процедуры зависит от `AUTO_CALIBRATE`.

На концевике прошивка не измеряет положение, а записывает в счётчик константу:
`500` на одном конце и `9500` на другом. Между ними 9000 шагов, тогда как клапан
проходит около 6000, поэтому шкала «от константы до константы» открывала клапан
примерно в полтора раза сильнее запрошенного (50% превращались в ~75%). Backend
измеряет фактический ход во время калибровки и считает проценты по нему.

Калибровка каждого регулятора — ровно два прохода: MIN, затем MAX (он же измеряет
ход), после чего одна относительная команда возвращает прежнее открытие. Третий
проход MIN больше не нужен. У первого мотора после инверсии DIR константы
записываются наоборот (`min` → `9500`, `max` → `500`), и его счётчик во время
работы выходит за обе константы — backend опирается на последнюю записанную
константу и считает шаги от неё, отдельного переключателя для этого нет.

Формат сохранённой калибровки — schema 4. Файлы прежних версий не читаются: в них
не было измеренного хода. После обновления панель попросит перекалибровку и до
неё клапаны не двигает.

## Развёртывание на NAS (bob)

Контейнер на Synology создаётся через Container Manager. Подготовленный compose,
скрипт синхронизации исходников и пошаговая инструкция лежат в
[`../deploy/bob/`](../deploy/bob/README.md). Панель там слушает порт **8088**
(8080 на bob занят vaultwarden), калибровочные данные хранятся в
`/volume1/docker/dacha-temp/data`, а `AUTO_CALIBRATE` выключен, чтобы
перезапуск контейнера не двигал клапаны сам по себе.

Обновление одной командой — `./deploy/bob/deploy.sh`: копирует исходники,
пересобирает образ, перезапускает контейнер и проверяет, что отвечает уже новая
сборка. Просто «Start» в Container Manager без «Build» оставляет старый образ,
поэтому внизу страницы показаны версия, коммит и время сборки, а
`curl -s http://bob:8088/api/version` отвечает на тот же вопрос из терминала.

## Локальная разработка

Требуется Node.js 22+.

```sh
npm ci
cp .env.example .env
npm run dev
```

В отдельной консоли доступны проверки:

```sh
npm run lint
npm run typecheck
npm test
npm run build
```

Адрес Arduino остаётся только в серверной конфигурации: браузер обращается к
`/api`, поэтому CORS прошивки не используется. Команды MIN/MAX и процентные
команды подтверждают лишь приём, а не достижение механической позиции. Сервер не
повторяет их автоматически.

Backend не выполняет фонового polling Arduino в idle-режиме. Обычный запрос
`/status` приходит от открытой панели раз в 5 секунд, а во время движения — раз
в 300 ms. Явно запущенная калибровка является исключением: ей нужен временный
частый polling для безопасного завершения этапов. Изменения счётчиков, сделанные
штатным энкодером контроллера, сохраняются как новое последнее положение.

## Диагностика

- «Нет связи» — проверьте IP, питание и доступность Arduino из Docker-сети.
- «Шкала не откалибрована» — дождитесь автоматической процедуры или нажмите
  «Перекалибровать».
- Значение `—` у температуры означает недостоверный ответ датчика (`-127°C`,
  стартовые `85°C` и физически невозможные величины скрываются).
- Поворот вала вручную без запуска мотора нельзя обнаружить текущим
  оборудованием. После него выполните ручную перекалибровку.

Подтверждённый mapping датчиков: `fl1` — первый этаж, `fl2` — второй этаж,
`boiler` — температура воды котла, `room` — бойлерная комната. Смысл MIN/MAX
следует подтверждать по чек-листу в плане.

Project documentation:

- [Design options](../docs/webapp-design-options.md) — mobile UI concepts and selection criteria.
- [Development plan](../docs/webapp-development-plan.md) — architecture, API contract, delivery phases, acceptance criteria, and implementation checklist.

The current Arduino firmware remains in `../controller` and is not modified by
the web application work unless a plan item explicitly calls for a separate,
size-checked firmware change.

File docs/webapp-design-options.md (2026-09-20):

# Варианты дизайна мобильного приложения регулятора

Статус документа: **выбран вариант A «Домашняя панель»**.

## 1. Общие требования ко всем вариантам

Приложение проектируется прежде всего для телефона шириной от 320 px и должно
нормально работать как в мобильном браузере, так и после добавления на домашний
экран. Главный экран содержит только то, что нужно для ежедневного контроля:

- температуру первого этажа;
- температуру второго этажа;
- температуру в бойлерной комнате;
- температуру входящей воды от котла;
- отдельное управление первым и вторым регулятором командами `MIN` и `MAX`;
- отображение текущего открытия в процентах после успешной калибровки;
- постепенную установку открытия с шагом 5% и выбор произвольной цели ползунком;
- состояние связи с контроллером и время последнего успешного обновления;
- понятную индикацию отправки команды, успеха и ошибки.

Общие принципы:

- крупные зоны нажатия не менее 44×44 px;
- значения температуры читаются без приближения экрана;
- кнопки двух этажей визуально и пространственно разделены;
- цвет не является единственным способом различить состояние;
- `MIN` и `MAX` называются именно так, пока не подтверждено, что они однозначно
  соответствуют «закрыть» и «открыть» для обеих физических установок;
- потенциально случайная команда подтверждается повторным действием или
  коротким диалогом;
- интерфейс показывает недостоверное/устаревшее значение явно, а не оставляет
  старую температуру выглядеть как актуальную.

## 2. Выбранный вариант A — «Домашняя панель»

Спокойный светлый интерфейс. Сверху — компактный статус связи и две инженерные
температуры, ниже — две большие карточки этажей. В каждой карточке крупно
показана температура этажа и рядом находятся две широкие кнопки `MIN`/`MAX`.
После калибровки карточка также показывает процент открытия и даёт постепенно
изменить целевое значение.

Предлагаемая модель управления процентом:

- крупное текущее значение, например «Открыто 42%»;
- кнопки `−5%` и `+5%` меняют только подготовленную цель, но не двигают клапан
  при каждом нажатии;
- ползунок позволяет быстро выбрать любое значение от 0 до 100%;
- отдельная кнопка «Установить 55%» отправляет одну команду после подтверждения;
- `MIN` и `MAX` остаются быстрыми действиями и также требуют подтверждения;
- во время калибровки процентные элементы отключены, вместо процента показан
  текущий этап и общий прогресс;
- при утрате калибровки карточка не показывает вычисленный процент и сообщает
  «Требуется калибровка».

Сильные стороны:

- все четыре температуры и оба регулятора видны без переходов;
- удобно быстро сравнивать этажи;
- интерфейс понятен членам семьи без технических знаний;
- хорошо масштабируется, если позднее появятся графики или автоматический режим.

Компромиссы:

- карточки занимают больше вертикального места;
- на очень маленьком экране нижняя часть второй карточки может потребовать
  небольшой прокрутки.

Рекомендуется, если приложение будет обычной домашней панелью и им будут
пользоваться несколько людей.

## 3. Вариант B — «Один этаж в фокусе»

В верхней части находятся четыре компактных показателя температуры. Ниже —
переключатель «1 этаж / 2 этаж», после которого показывается только выбранный
регулятор, его температура, позиция и две очень крупные кнопки `MIN`/`MAX`.

Сильные стороны:

- самые крупные и безопасные органы управления;
- удобно пользоваться одной рукой;
- меньше риск нажать кнопку не того этажа;
- хорошо подходит для узких экранов.

Компромиссы:

- состояние второго регулятора скрыто за переключателем;
- для управления обоими этажами требуется дополнительное действие;
- сравнение этажей менее наглядно.

Рекомендуется, если чаще всего регулируется только один этаж за раз, а защита от
ошибочного нажатия важнее одновременного обзора.

## 4. Вариант C — «Инженерная консоль»

Контрастная тёмная панель высокой плотности. Четыре температуры собраны в сетку,
регуляторы представлены компактными строками с позицией, индикатором движения и
кнопками `MIN`/`MAX`. Служебный статус связи заметнее, чем в остальных вариантах.

Сильные стороны:

- максимум информации помещается на одном экране;
- хорошо читается в тёмном техническом помещении;
- удобно диагностировать связь и состояние устройства;
- естественно расширяется служебными данными.

Компромиссы:

- выглядит более технически;
- плотная компоновка менее дружелюбна для случайного пользователя;
- для солнечного света потребуется тщательно проверить контрастность.

Рекомендуется, если приложением в основном пользуется владелец системы и важна
диагностическая информация.

## 5. Принятое решение

Владелец проекта выбрал **вариант A**. Варианты B и C сохранены выше только как
история рассмотренных решений. Если отдельного решения по теме не будет, следует
использовать автоматическую тему по настройке телефона с качественной светлой
версией по умолчанию.

## 6. Состояния выбранного интерфейса

Карточка регулятора должна иметь четыре взаимоисключающих состояния:

1. `CALIBRATING` — показан этап `MIN`/`MAX`, номер регулятора и общий прогресс;
   ручные команды заблокированы.
2. `READY` — показаны текущий процент, позиция в шагах, выбор цели и действия
   `MIN`/`MAX`.
3. `MOVING` — показаны текущий и целевой проценты; повторные команды этому
   регулятору заблокированы.
4. `UNCALIBRATED/ERROR` — процент скрыт, причина понятна, доступно действие
   «Повторить калибровку».

Калибровка обоих регуляторов выполняется последовательно, потому что концевики
общие. Глобальный статус калибровки располагается над карточками этажей и не
вытесняет четыре температурные метрики.

## 7. Не принятые пока продуктовые решения

Эти вопросы не блокируют выбор визуального варианта, но должны быть закрыты до
финальной приёмки:

1. Подтвердить физическое соответствие `MIN` и `MAX` открытию/закрытию каждого
   клапана.
2. Подтвердить соответствие индексов датчиков полям `fl1`, `fl2`, `boiler`,
   `room`. Текущая прошивка использует порядок обнаружения OneWire, а не адреса
   датчиков, поэтому порядок может оказаться нестабильным после замены датчика.
3. Решить, требуется ли авторизация в домашней сети. Базовый план исходит из
   доверенной локальной сети и не публикует приложение в интернет.
4. Решить, нужна ли установка как PWA. В плане это вынесено в отдельный этап и
   не требуется для первого рабочего релиза.
5. Выбрать положение клапанов после автоматической калибровки: восстановить
   последние целевые проценты, перейти в `MIN` или остаться в `MAX`. Реализация
   не должна молча выбирать это поведение.

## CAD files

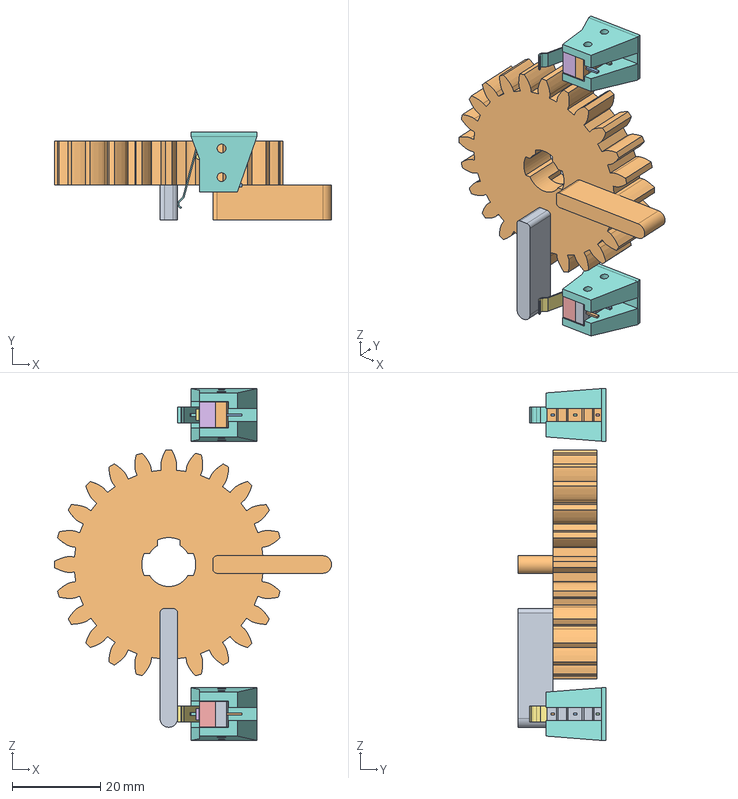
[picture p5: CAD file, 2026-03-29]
3D_models/gears-v2.FCStd
63.0 x 20.0 x 80.0 mm
Bottom
Pin_NC
Pin_NO
Pin_C
Top
Button
Lever
Bottom001
Pin_NC001
Pin_NO001
Pin_C001
Top001
Button001
Lever001
endstop-case
limit-arm

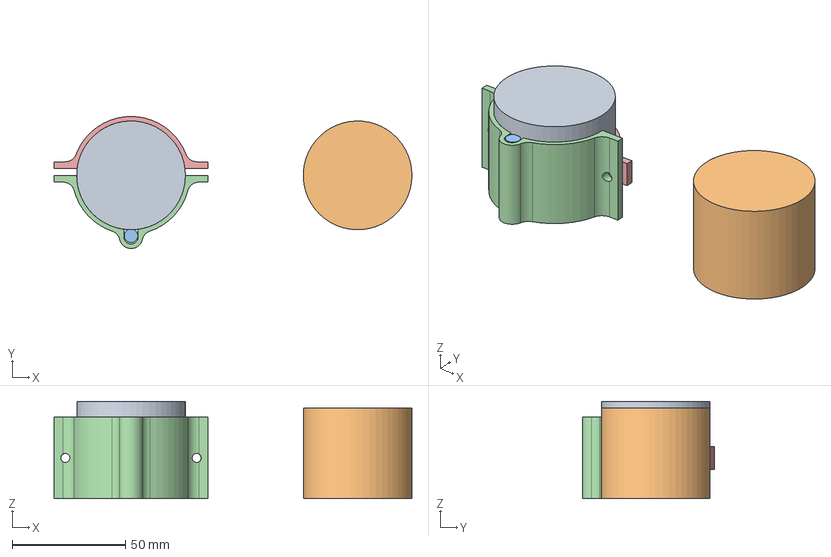
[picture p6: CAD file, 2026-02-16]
3D_models/sensor_mount2.FCStd
158.0 x 58.3 x 43.0 mm
p1
p-boiler
DS1820
m1
m2

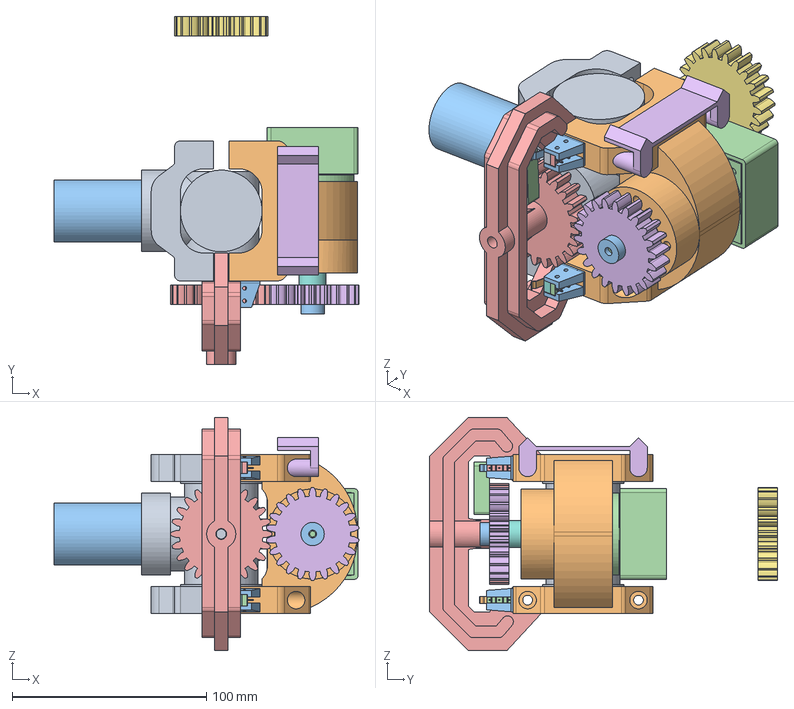
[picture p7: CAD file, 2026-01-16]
3D_models/device.FCStd
156.8 x 179.0 x 120.0 mm
DN25
arm
left-pipe
motor001
gear-valve
gear-motor
InvoluteGear001
right-ring
ushi-back
whole-body
gear-cap
reductr-motr
Bottom
Pin_NC
Pin_NO
Pin_C
Top
Button
Lever
Bottom001
Pin_NC001
Pin_NO001
Pin_C001
Top001
Button001
Lever001
endstop-case
limit-arm
Gear frame
CableHolder

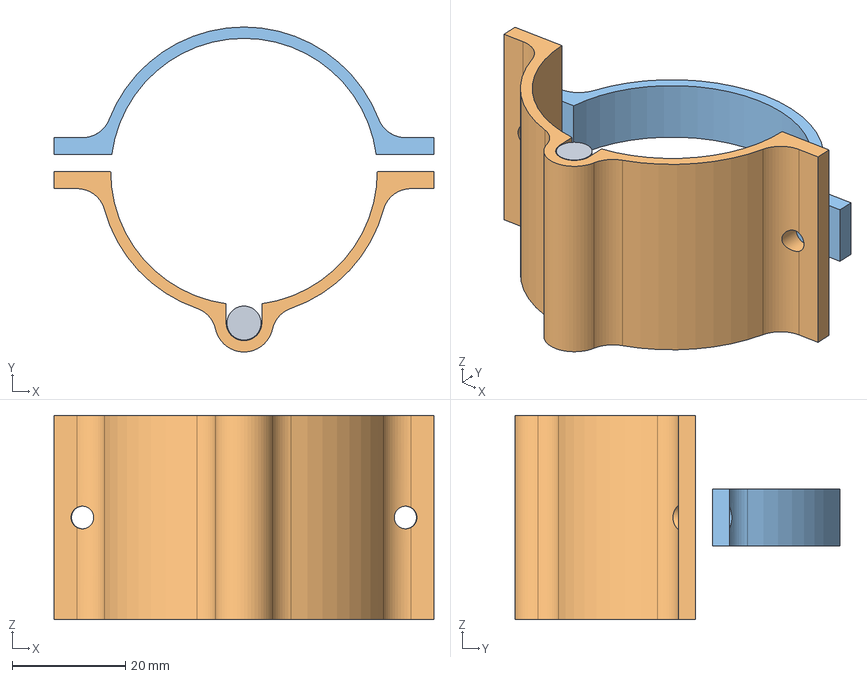
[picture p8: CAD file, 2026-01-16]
3D_models/sensor_mount.FCStd
67.0 x 57.3 x 36.0 mm
DS1820
m1
m2

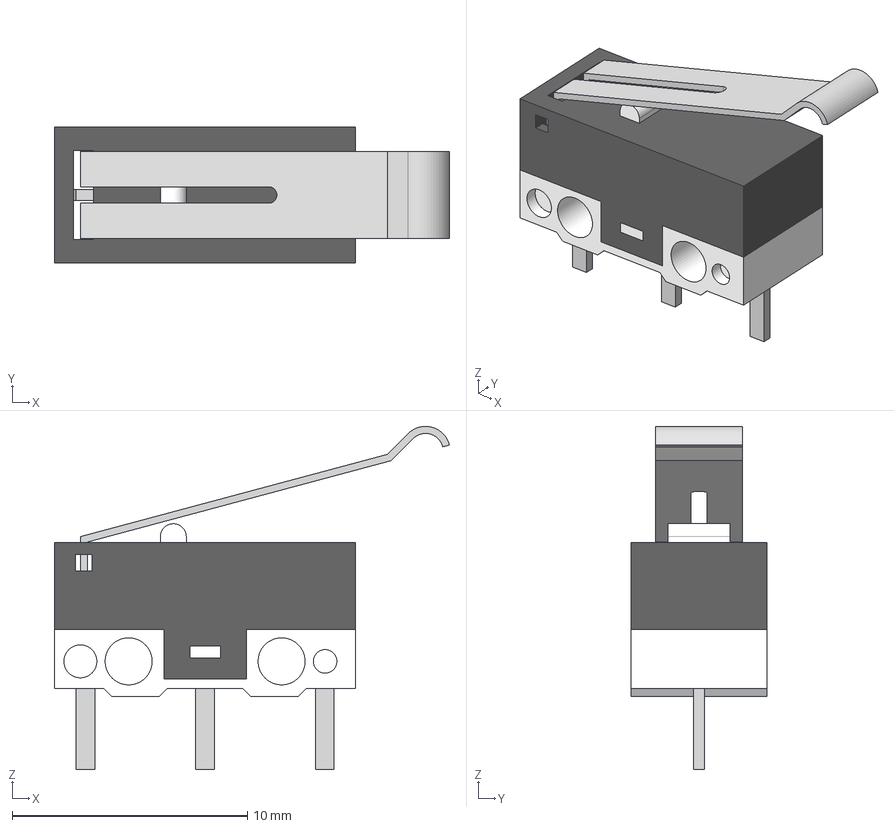
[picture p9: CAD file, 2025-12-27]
3D_models/Microswitch_SPDT_Vertical.FCStd
16.8 x 5.80 x 14.6 mm
Bottom
Pin_NC
Pin_NO
Pin_C
Top
Button
Lever

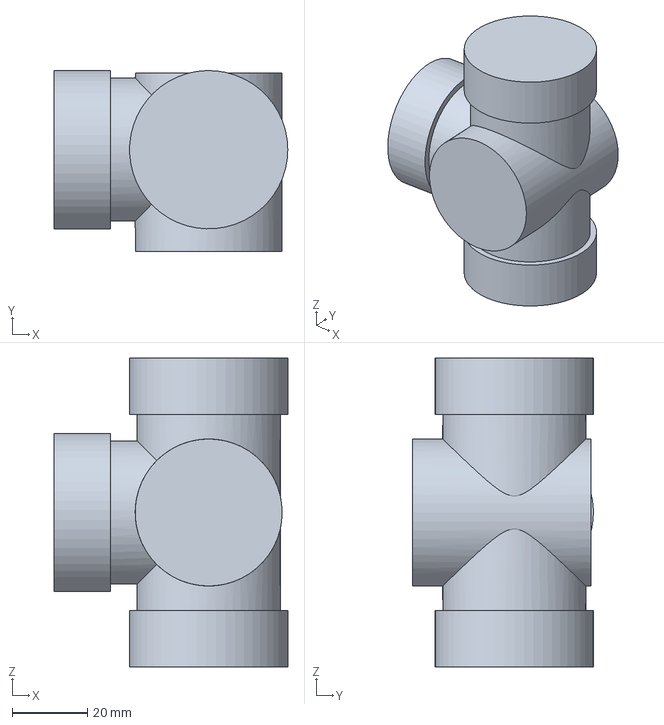
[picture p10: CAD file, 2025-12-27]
3D_models/EBSE_VRG131.FCStd
62.0 x 48.0 x 82.0 mm

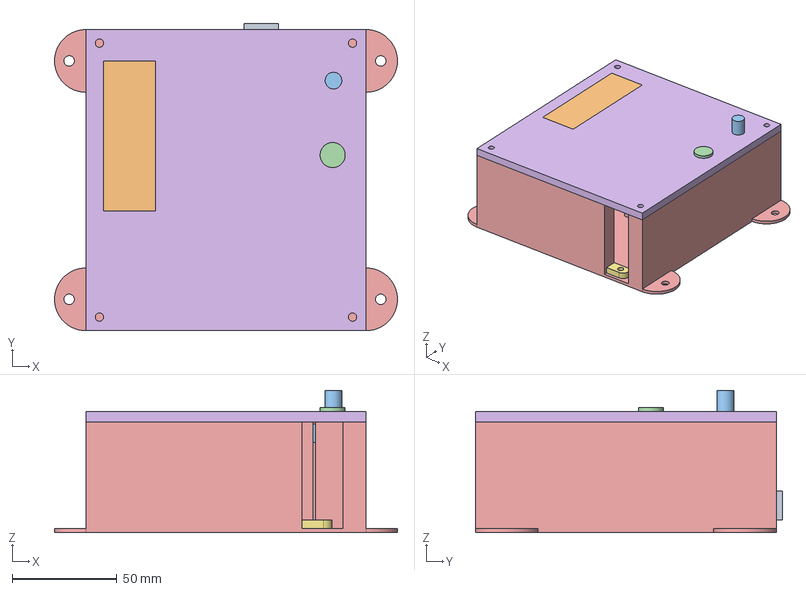
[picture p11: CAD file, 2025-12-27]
3D_models/case.FCStd
164.0 x 147.0 x 68.0 mm
Arduino
LCD
Encoder
Button
Case
CaseTop
cable-holder

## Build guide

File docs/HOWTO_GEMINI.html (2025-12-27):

This is a sophisticated DIY project involving motion control, networking, user interface, and sensor integration.

Below is a complete guide covering compatibility, PlatformIO setup, code structure, and wiring.

### 1. Device Compatibility Check (Critical)

There is a Major Hardware Conflict in your component list that requires a specific workaround.

● The Conflict: You are using an Arduino Leonardo. On the Leonardo, the I2C pins (SDA, SCL) are located on Digital Pins 2 and 3.

● ** The Problem:** The CNC Shield R3 is designed for the Arduino Uno. It hardwires the X-Axis and Y-Axis stepper drivers to Pins 2, 3, 5, and 6.

○ If you use the X and Y slots for your motors, you cannot use the I2C LCD because the pins are occupied by the motors.

● The Solution: You must use the Z-Axis and A-Axis slots on the CNC Shield for your two motors.

○ Z-Axis uses Pins 4 and 7.

○ A-Axis uses Pins 12 and 13.

○ This leaves Pins 2 and 3 free for your LCD Display.

Correction on Sensors: You mentioned "three I2C temperature sensors (DS18B20)". The DS18B20 is NOT an I2C sensor; it uses the OneWire protocol. This is fine, but you cannot connect them to the I2C bus. They will need a separate digital pin (e.g., A0) and a 4.7kΩ pull-up resistor.

### 2. PlatformIO Setup Guide

1. Install VS Code and the PlatformIO IDE extension.

2. Click the Alien Icon on the left sidebar -> Create New Project.

3. Name: HeaterValveControl

4. Board: Arduino Leonardo ETH (or just Arduino Leonardo if the ETH version isn't explicitly listed, the processor is the same).

5. Framework: Arduino.

Once created, open your platformio.ini file and replace the content with this configuration:

Ini, TOML

[env:leonardoeth]
platform = atmelavr
board = leonardoeth
framework = arduino
monitor_speed = 115200

; Library Dependencies
lib_deps =
marcoschwartz/LiquidCrystal_I2C @ ^1.1.4
paulstoffregen/OneWire @ ^2.3.7
milesburton/DallasTemperature @ ^3.11.0
waspinator/AccelStepper @ ^1.64
arduino-libraries/Ethernet @ ^2.0.0

### 3. Logic Modules and Code

We will split the code into logical parts. Create a src/main.cpp file.

Key Logic Flow:

1. Setup: Init Ethernet, LCD, Sensors.

2. Homing: Motors move towards endstops. Count steps. Once hit, move back the same amount.

3. Loop:

○ Check HTTP Client (Ethernet).

○ Read Encoder/Buttons.

○ Update LCD (based on menu state).

○ Run Steppers (must be called frequently).

○ Read Temperatures (periodically, not every loop).

#### The Code (src/main.cpp)

C++

#include <Arduino.h>
#include <SPI.h>
#include <Ethernet.h>
#include <Wire.h>
#include <LiquidCrystal_I2C.h>
#include <OneWire.h>
#include <DallasTemperature.h>
#include <AccelStepper.h>

// --- CONFIGURATION ---
// MAC Address (sticker on your board or make one up)
byte mac[] = { 0xDE, 0xAD, 0xBE, 0xEF, 0xFE, 0xED };
IPAddress ip(192, 168, 1, 177); // Manual IP

// Pins (Mapped for Leonardo + CNC Shield Z/A Axis workaround)
#define ONE_WIRE_BUS A0 // DS18B20 Data pin
#define BUTTON_PIN A1 // Menu Button
#define ENCODER_A A2
#define ENCODER_B A3

// Stepper 1 (Valve 1) - Using Z Axis Driver Slot
#define M1_STEP_PIN 4
#define M1_DIR_PIN 7
#define M1_ENDSTOP 11 // Z- limit pin on shield

// Stepper 2 (Valve 2) - Using A Axis Driver Slot
#define M2_STEP_PIN 12
#define M2_DIR_PIN 13
#define M2_ENDSTOP 9 // SpnEn (often used for A) or reuse X/Y limits (9/10). *Check wiring below*

// Settings
#define MAX_POSITION 2000 // Max steps allowed away from endstop
#define HOMING_SPEED 200.0
#define RUN_SPEED 400.0
#define ACCEL 200.0

// --- OBJECTS ---
EthernetServer server(80);
LiquidCrystal_I2C lcd(0x27, 16, 2);
OneWire oneWire(ONE_WIRE_BUS);
DallasTemperature sensors(&oneWire);

// 1 = Driver Interface
AccelStepper stepper1(AccelStepper::DRIVER, M1_STEP_PIN, M1_DIR_PIN);
AccelStepper stepper2(AccelStepper::DRIVER, M2_STEP_PIN, M2_DIR_PIN);

// Global Variables
enum MenuState { STATE_DEFAULT, STATE_EDIT_M1, STATE_EDIT_M2 };
MenuState currentState = STATE_DEFAULT;

float temp1 = 0, temp2 = 0, temp3 = 0;
long lastTempTime = 0;
int lastEncoderVal = 0; // Simple polling for encoder

// Button Debounce
int lastButtonState = HIGH;
unsigned long lastDebounceTime = 0;

void homingRoutine(AccelStepper &stepper, int endstopPin) {
// Move until endstop is hit
stepper.setMaxSpeed(HOMING_SPEED);
stepper.setSpeed(-HOMING_SPEED); // Move towards minimal

long stepsCounted = 0;

// Keep running until switch is triggered (assuming LOW when pressed)
// Note: Add a safety timeout in production code!
while (digitalRead(endstopPin) == HIGH) {
stepper.runSpeed();
stepsCounted++;
delayMicroseconds(100); // Small delay to allow mechanics to move
}

stepper.setCurrentPosition(0); // This is now position 0

// "Return back counted steps to restore actual position"
// NOTE: This logic assumes the valve was open X steps before power loss.
// Since we don't know where it was before power loss, we can only
// move it to a safe default OR stay at 0.
// If you meant "Measure how far we moved to hit the wall, then go back":

stepper.moveTo(stepsCounted);
while(stepper.distanceToGo() != 0) {
stepper.run();
}
}

void setup() {
// 1. Init Serial
Serial.begin(115200);

// 2. Init Pins
pinMode(M1_ENDSTOP, INPUT_PULLUP);
pinMode(M2_ENDSTOP, INPUT_PULLUP);
pinMode(BUTTON_PIN, INPUT_PULLUP);
pinMode(ENCODER_A, INPUT_PULLUP);
pinMode(ENCODER_B, INPUT_PULLUP);

// 3. Init LCD
lcd.init();
lcd.backlight();
lcd.setCursor(0,0);
lcd.print("Init System...");

// 4. Init Sensors
sensors.begin();

// 5. Init Steppers
stepper1.setMaxSpeed(RUN_SPEED);
stepper1.setAcceleration(ACCEL);
stepper2.setMaxSpeed(RUN_SPEED);
stepper2.setAcceleration(ACCEL);

// 6. Homing
lcd.setCursor(0,1);
lcd.print("Homing M1...");
homingRoutine(stepper1, M1_ENDSTOP);

lcd.setCursor(0,1);
lcd.print("Homing M2...");
homingRoutine(stepper2, M2_ENDSTOP);

// 7. Init Ethernet
Ethernet.begin(mac, ip);
server.begin();

lcd.clear();
}

void handleWeb() {
EthernetClient client = server.available();
if (client) {
boolean currentLineIsBlank = true;
String header = "";
while (client.connected()) {
if (client.available()) {
char c = client.read();
if (header.length() < 100) header += c;

if (c == '\n' && currentLineIsBlank) {
// Parse request
// Example: GET /?m1=1000 HTTP/1.1
int idxM1 = header.indexOf("m1=");
int idxM2 = header.indexOf("m2=");

if(idxM1 > 0) {
int val = header.substring(idxM1+3).toInt();
if(val >= 0 && val <= MAX_POSITION) stepper1.moveTo(val);
}
if(idxM2 > 0) {
int val = header.substring(idxM2+3).toInt();
if(val >= 0 && val <= MAX_POSITION) stepper2.moveTo(val);
}

// Send Response
client.println("HTTP/1.1 200 OK");
client.println("Content-Type: text/plain");
client.println("Connection: close");
client.println();
client.print("T1:"); client.print(temp1);
client.print("|T2:"); client.print(temp2);
client.print("|T3:"); client.print(temp3);
client.print("|M1:"); client.print(stepper1.currentPosition());
client.print("|M2:"); client.print(stepper2.currentPosition());
break;
}
if (c == '\n') currentLineIsBlank = true;
else if (c != '\r') currentLineIsBlank = false;
}
}
delay(1);
client.stop();
}
}

void readEncoder() {
// Basic rotary encoder logic
static int lastA = HIGH;
int currentA = digitalRead(ENCODER_A);

if (lastA == HIGH && currentA == LOW) {
int change = 0;
if (digitalRead(ENCODER_B) == LOW) change = 50; // Clockwise
else change = -50; // Counter-Clockwise

if (currentState == STATE_EDIT_M1) {
long newPos = stepper1.targetPosition() + change;
if(newPos >= 0 && newPos <= MAX_POSITION) stepper1.moveTo(newPos);
}
else if (currentState == STATE_EDIT_M2) {
long newPos = stepper2.targetPosition() + change;
if(newPos >= 0 && newPos <= MAX_POSITION) stepper2.moveTo(newPos);
}
}
lastA = currentA;
}

void handleMenu() {
// Read Button
int reading = digitalRead(BUTTON_PIN);
if (reading == LOW && lastButtonState == HIGH && millis() - lastDebounceTime > 50) {
// Toggle State
if(currentState == STATE_DEFAULT) currentState = STATE_EDIT_M1;
else if(currentState == STATE_EDIT_M1) currentState = STATE_EDIT_M2;
else currentState = STATE_DEFAULT;
lcd.clear();
lastDebounceTime = millis();
}
lastButtonState = reading;

// Display Logic
static long lastLCDUpdate = 0;
if(millis() - lastLCDUpdate > 200) {
if(currentState == STATE_DEFAULT) {
lcd.setCursor(0,0);
lcd.print(temp1, 1); lcd.print(" P1:"); lcd.print(stepper1.currentPosition());
lcd.setCursor(0,1);
lcd.print(temp3, 1); lcd.print(" P2:"); lcd.print(temp2, 1); // Layout as requested
} else if (currentState == STATE_EDIT_M1) {
lcd.setCursor(0,0); lcd.print(">> EDIT MOTOR 1");
lcd.setCursor(0,1); lcd.print("Pos: "); lcd.print(stepper1.targetPosition());
} else {
lcd.setCursor(0,0); lcd.print(">> EDIT MOTOR 2");
lcd.setCursor(0,1); lcd.print("Pos: "); lcd.print(stepper2.targetPosition());
}
lastLCDUpdate = millis();
}
}

void loop() {
// 1. Critical: Run Steppers (must happen as fast as possible)
stepper1.run();
stepper2.run();

// 2. Read Temps (Every 2 seconds)
if(millis() - lastTempTime > 2000) {
sensors.requestTemperatures();
temp1 = sensors.getTempCByIndex(0);
temp2 = sensors.getTempCByIndex(1);
temp3 = sensors.getTempCByIndex(2);
lastTempTime = millis();
}

// 3. Handle Inputs
handleWeb();
readEncoder();
handleMenu();
}

### 4. Wiring Connection Guide

This is the most complex part due to the Leonardo/CNC Shield conflict. You must ignore the labels "X" and "Y" on the shield.

#### A. CNC Shield & Motors

Insert the A4988 drivers into the Z and A slots. (Ensure the potentiometer on the driver faces away from the axis pins, check your shield version).

Component | CNC Shield/Arduino Pin | Description
Motor 1 (Stepper) | Z-Axis Header | Connect 4 wires of Motor 1 here
Motor 2 (Stepper) | A-Axis Header | Connect 4 wires of Motor 2 here
Motor 1 Endstop | Z- (Pin 11) | Connect Switch between Z- (White) and GND (Black)
Motor 2 Endstop | SpnEn (Pin 12) or D9 | The A-axis pins are tricky on generic shields. Recommendation: Connect the endstop directly to Arduino Pin 9 and GND (solder to the header pins sticking out of the shield). Update code: #define M2_ENDSTOP 9
External Power | Blue Terminal Block | Connect 12V-24V Power Supply (Required for motors)

#### B. Sensors (DS18B20)

Do not plug these into I2C.

1. Connect all VCC pins to +5V.

2. Connect all GND pins to GND.

3. Connect all Data pins together to Arduino Analog Pin A0.

4. Crucial: Place a 4.7kΩ resistor between the Data line and VCC (+5V).

#### C. LCD (I2C)

1. SDA: Connect to Arduino Pin 2.

2. SCL: Connect to Arduino Pin 3.

3. VCC: +5V.

4. GND: GND.
(Note: Because we used Z/A slots for motors, pins 2 and 3 are free for this!)

#### D. Controls (Encoder & Button)

1. Menu Button: One side to A1, other side to GND.

2. Encoder A: To A2.

3. Encoder B: To A3.

4. Encoder GND: To GND.

### Next Step

Would you like me to explain how to specifically identify the "A-axis" pins on your specific version of the CNC shield, or verify the color coding for your stepper motor wires?

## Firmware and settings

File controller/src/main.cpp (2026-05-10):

#include <Arduino.h>
#include <SPI.h>
#include <Ethernet.h>
#include <Wire.h>
#include <LiquidCrystal_I2C.h>
#include <OneWire.h>
#include <DallasTemperature.h>
#include <AccelStepper.h>
#include <EEPROM.h>  // Lightweight library for saving IP

// --- PIN DEFINITIONS ---
#define ONE_WIRE_BUS    A0
#define BUTTON_PIN      A1
#define ENCODER_A       A2
#define ENCODER_B       A3

#define PIN_COMMON_MIN  11 // Z- Z+
#define PIN_COMMON_MAX  9 // X- X+

// WARNING: Pin 4 is often used by Ethernet Shield for SD Card CS.
// If your shield has an SD slot, ensure it doesn't conflict.
#define M1_STEP_PIN     4
#define M1_DIR_PIN      7
#define M2_STEP_PIN     12
#define M2_DIR_PIN      13
#define EN_PIN          8

#define RUN_SPEED         1000
#define ACCEL             7000

// --- CONSTANTS ---
const unsigned long DEBOUNCE_DELAY = 300;
const int ENCODER_TURN_STEP = 500; // how many motor steps per one click
const int BACKOFF_STEPS = 500;
const long MAX_POSITION_LIMIT = 10000;
const long SAFETY_RUN_LIMIT = 20000;
// Direction multiplier: -1 for motors with setPinsInverted, 1 for normal
const int M1_DIR = -1;
const int M2_DIR =  1;
const static char TRAILING_CHARS[] = "      ";

LiquidCrystal_I2C lcd(0x27, 16, 2);

OneWire oneWire(ONE_WIRE_BUS);
DallasTemperature sensors(&oneWire);
float temp1 = 0.0, temp2 = 0.0, temp3 = 0.0, temp4 = 0.0;

// MOTORS
AccelStepper motor1(AccelStepper::DRIVER, M1_STEP_PIN, M1_DIR_PIN);
AccelStepper motor2(AccelStepper::DRIVER, M2_STEP_PIN, M2_DIR_PIN);

// ETHERNET
byte mac[] = { 0x90, 0xA2, 0xDA, 0x10, 0xE2, 0x24 };
IPAddress staticIP(192, 168, 88, 20);
EthernetServer server(80);

// --- STATE VARIABLES ---
// Simplified State Machine
enum UIState { SCREEN_DASHBOARD, SCREEN_CONTROL_M1, SCREEN_CONTROL_M2 };
UIState currentScreen = SCREEN_DASHBOARD;

unsigned long lastButtonPress = 0;
int lastEncoderA = LOW;

bool motorsEnabled = false;
bool isBackingOff = false;
bool minLocked = false; // endstop was hit, ignore until released
bool maxLocked = false;

unsigned long lastTempUpdate = 0;
const long TEMP_UPDATE_INTERVAL = 5000;

// Heartbeat variables
unsigned long lastHeartbeat = 0;
char heartbeatChar = '*';

// --- FUNCTION PROTOTYPES ---
void handleNetwork();
void readSensors();
void handleInput();
void updateLCD();
void manageMotors();
void triggerBackoff(AccelStepper &motor, int direction, int pin);
void checkEndstops(AccelStepper &motor, int dir, bool minHit, bool maxHit);
void enableMotors(bool enable);
void loadIP(void);
void parseAndSaveIP(char* buffer);

void setup() {
    // Serial removed to save space

    pinMode(BUTTON_PIN, INPUT_PULLUP);
    pinMode(ENCODER_A, INPUT_PULLUP);
    pinMode(ENCODER_B, INPUT_PULLUP);

    pinMode(PIN_COMMON_MIN, INPUT_PULLUP);
    pinMode(PIN_COMMON_MAX, INPUT_PULLUP);

    pinMode(EN_PIN, OUTPUT);
    enableMotors(false);

    lcd.init();
    lcd.backlight();
    lcd.setCursor(6,0);
    lcd.print(F("(ZK)"));
    lcd.setCursor(5,1);
    lcd.print(F("welcome"));
    delay(1000);

    sensors.begin();

    motor1.setMaxSpeed(RUN_SPEED); motor1.setAcceleration(ACCEL);
    motor1.setPinsInverted(true, false, false); // Reverse direction for 1st floor valve
    motor2.setMaxSpeed(RUN_SPEED); motor2.setAcceleration(ACCEL);

    // Load IP from EEPROM
    loadIP();
    Ethernet.begin(mac, staticIP);
    server.begin();

    // 5. SHOW IP ON BOOT
    // It is critical to show the user the IP so they know where to connect
    lcd.clear();
    lcd.setCursor(0,0);
    lcd.print(F("IP Address:"));
    lcd.setCursor(0,1);
    lcd.print(Ethernet.localIP());
    delay(4000); // Show IP for 3 seconds before going to dashboard

    lcd.clear();
}

void loop() {
    readSensors();
    handleInput();
    handleNetwork();
    manageMotors();
    updateLCD();
}

// --- EEPROM LOGIC ---

void loadIP() {
    // Read 4 bytes from EEPROM addresses 0,1,2,3
    byte ip0 = EEPROM.read(0);
    byte ip1 = EEPROM.read(1);
    byte ip2 = EEPROM.read(2);
    byte ip3 = EEPROM.read(3);

    // Basic validity check: if first byte is 0 or 255, assume empty/invalid
    if (ip0 == 0 || ip0 == 255) {
        // Fallback Default
        staticIP = IPAddress(192, 168, 88, 20);
    } else {
        staticIP = IPAddress(ip0, ip1, ip2, ip3);
    }
}

void parseAndSaveIP(char* buffer) {
    // Expected format: GET /setip?ip=192.168.1.55
    char* ipStart = strstr(buffer, "ip=");
    if (!ipStart) return;

    ipStart += 3; // Move past "ip="

    int bytes[4] = {0, 0, 0, 0};
    int byteIdx = 0;

    // Simple manual parsing to avoid String library
    // Scan until space or end of line
    while (*ipStart != ' ' && *ipStart != '\0' && byteIdx < 4) {
        if (*ipStart == '.') {
            byteIdx++;
        } else if (*ipStart >= '0' && *ipStart <= '9') {
            bytes[byteIdx] = (bytes[byteIdx] * 10) + (*ipStart - '0');
        }
        ipStart++;
    }

    // Save to EEPROM
    EEPROM.write(0, bytes[0]);
    EEPROM.write(1, bytes[1]);
    EEPROM.write(2, bytes[2]);
    EEPROM.write(3, bytes[3]);
}

void enableMotors(bool enable) {
    digitalWrite(EN_PIN, enable ? LOW : HIGH);
    motorsEnabled = enable;
}

void manageMotors() {
    // Auto-enable logic
    if ((motor1.distanceToGo() != 0 || motor2.distanceToGo() != 0) && !motorsEnabled) {
        enableMotors(true);
    } else if (motor1.distanceToGo() == 0 && motor2.distanceToGo() == 0 && motorsEnabled) {
        enableMotors(false);
    }

    bool minHit = (digitalRead(PIN_COMMON_MIN) == LOW);
    bool maxHit = (digitalRead(PIN_COMMON_MAX) == LOW);

    // Clear lock once endstop is physically released
    if (!minHit) minLocked = false;
    if (!maxHit) maxLocked = false;

    if (motor1.distanceToGo() != 0) {
        motor1.run();
        checkEndstops(motor1, M1_DIR, minHit, maxHit);
    }
    else if (motor2.distanceToGo() != 0) {
        motor2.run();
        checkEndstops(motor2, M2_DIR, minHit, maxHit);
    }
}

// Generic endstop handler. dir = 1 for normal motor, -1 for inverted.
// Uses distanceToGo() instead of speed() — speed can be 0 during accel ramp.
void checkEndstops(AccelStepper &motor, int dir, bool minHit, bool maxHit) {
    long dtg = motor.distanceToGo() * dir;
    if (minHit && !minLocked && dtg < 0 && !isBackingOff) {
        triggerBackoff(motor, dir, PIN_COMMON_MIN);
        motor.setCurrentPosition(BACKOFF_STEPS);
        motor.moveTo(BACKOFF_STEPS);
        minLocked = true;
    }
    else if (maxHit && !maxLocked && dtg > 0 && !isBackingOff) {
        triggerBackoff(motor, -dir, PIN_COMMON_MAX);
        motor.setCurrentPosition(MAX_POSITION_LIMIT - BACKOFF_STEPS);
        motor.moveTo(MAX_POSITION_LIMIT - BACKOFF_STEPS);
        maxLocked = true;
    }
}

void triggerBackoff(AccelStepper &motor, int direction, int pin) {
    isBackingOff = true;
    
    // Step away slowly until the pin is released
    motor.setSpeed(direction * (RUN_SPEED / 2.0));
    while (digitalRead(pin) == LOW) {
        motor.runSpeed();
    }
    
    // Extra backoff to clear switch properly
    motor.setCurrentPosition(0);
    motor.moveTo(direction * BACKOFF_STEPS);
    while (motor.distanceToGo() != 0) {
        motor.run();
    }
    
    isBackingOff = false;
}
const int menuResetSeconds = 5*60;
int menuClearTimer = 0;

void handleInput() {
    // 1. Encoder (Moves motors directly if screen is selected)
    int currentA = digitalRead(ENCODER_A);
    if (currentA != lastEncoderA && currentA == LOW) {
        int currentB = digitalRead(ENCODER_B);
        int direction = (currentB != currentA) ? 1 : -1;

        if (currentScreen == SCREEN_CONTROL_M1) {
            if (!(direction * M1_DIR < 0 && minLocked) && !(direction * M1_DIR > 0 && maxLocked))
                motor1.move(direction * ENCODER_TURN_STEP);
        }
        else if (currentScreen == SCREEN_CONTROL_M2) {
            if (!(direction * M2_DIR < 0 && minLocked) && !(direction * M2_DIR > 0 && maxLocked))
                motor2.move(direction * ENCODER_TURN_STEP);
        }
        menuClearTimer = 0;
    }
    lastEncoderA = currentA;

    // 2. Button (Cycles Screens)
    if (digitalRead(BUTTON_PIN) == LOW) {
        if (millis() - lastButtonPress > DEBOUNCE_DELAY) {
            lastButtonPress = millis();

            // Cycle Logic: Dashboard -> M1 -> M2 -> Dashboard
            if (currentScreen == SCREEN_DASHBOARD) {
                currentScreen = SCREEN_CONTROL_M1;
            } else if (currentScreen == SCREEN_CONTROL_M1) {
                currentScreen = SCREEN_CONTROL_M2;
            } else {
                currentScreen = SCREEN_DASHBOARD;
            }

            lcd.clear();
        }
        menuClearTimer = 0;
    }
}



void updateLCD() {
    // Toggle Heartbeat every 1000ms
    if (millis() - lastHeartbeat > 1000) { // if changed, look at menuResetSeconds multiplicators
        lastHeartbeat = millis();
        if (heartbeatChar == '*') heartbeatChar = '+';
        else heartbeatChar = '*';
        menuClearTimer++;
    }

    static unsigned long lastLcdUpdate = 0;
    if (millis() - lastLcdUpdate < 200) return;
    lastLcdUpdate = millis();

    if (currentScreen == SCREEN_DASHBOARD) {
        lcd.setCursor(0, 0); lcd.print(F("F:")); lcd.print((int)temp1); lcd.print(TRAILING_CHARS);
        lcd.setCursor(6, 0); lcd.print(F("S:")); lcd.print((int)temp2); lcd.print(TRAILING_CHARS);
        lcd.setCursor(12, 0); lcd.print(F("B:")); lcd.print((int)temp3); lcd.print(TRAILING_CHARS);
        lcd.setCursor(0, 1); lcd.print(F("Room:")); lcd.print((int)temp4); lcd.print(TRAILING_CHARS);
        menuClearTimer = 0;
    }
    else if (currentScreen == SCREEN_CONTROL_M1) {
        lcd.setCursor(0, 0);
        lcd.print(F("First Floor"));
        lcd.setCursor(0, 1);
        lcd.print(F("Pos: ")); lcd.print(motor1.currentPosition());
        lcd.print(TRAILING_CHARS); // clear trailing chars
        if (menuClearTimer > menuResetSeconds) {
            currentScreen = SCREEN_DASHBOARD;
        }
    }
    else if (currentScreen == SCREEN_CONTROL_M2) {
        lcd.setCursor(0, 0);
        lcd.print(F("Second Floor"));
        lcd.setCursor(0, 1);
        lcd.print(F("Pos: ")); lcd.print(motor2.currentPosition());
        lcd.print(TRAILING_CHARS); // clear trailing chars
        if (menuClearTimer > menuResetSeconds) {
            currentScreen = SCREEN_DASHBOARD;
        }
    }

    // Always draw heartbeat at 15,1 (Bottom Right)
    lcd.setCursor(15, 1);
    lcd.print(heartbeatChar);
}

void readSensors() {
    if (motorsEnabled) {
        return;
    }
    if (millis() - lastTempUpdate > TEMP_UPDATE_INTERVAL) {
        lastTempUpdate = millis();
        sensors.requestTemperatures();
        temp1 = sensors.getTempCByIndex(0);
        temp2 = sensors.getTempCByIndex(1);
        temp3 = sensors.getTempCByIndex(2);
        temp4 = sensors.getTempCByIndex(3);
    }
}

void handleNetwork() {
    EthernetClient client = server.available();
    if (client) {
        boolean currentLineIsBlank = true;
        char buffer[100];
        int bufIdx = 0;

        while (client.connected()) {
            if (client.available()) {
                char c = client.read();
                if (bufIdx < 99 && c != '\r' && c != '\n') {
                    buffer[bufIdx++] = c;
                    buffer[bufIdx] = '\0';
                }

                if (c == '\n' && currentLineIsBlank) {
                    client.println(F("HTTP/1.1 200 OK"));
                    client.println(F("Content-Type: application/json"));
                    client.println(F("Connection: close"));
                    client.println();

                    if (strstr(buffer, "GET /status") != 0) {
                        client.print(F("{"));
                        client.print(F("\"fl1\":")); client.print(temp1); client.print(F(","));
                        client.print(F("\"fl2\":")); client.print(temp2); client.print(F(","));
                        client.print(F("\"boiler\":")); client.print(temp3); client.print(F(","));
                        client.print(F("\"room\":")); client.print(temp4); client.print(F(","));
                        client.print(F("\"m1\":")); client.print(motor1.currentPosition()); client.print(F(","));
                        client.print(F("\"m2\":")); client.print(motor2.currentPosition());
                        client.print(F("}"));
                    }
                    else if (strstr(buffer, "GET /setip") != 0) {
                        // GET /setip?ip=192.168.1.55
                        parseAndSaveIP(buffer);
                        client.print(F("{\"status\":\"saved_reboot\"}"));
                    }
                    else if (strstr(buffer, "GET /set") != 0) {
                        char* mPtr = strstr(buffer, "motor=");
                        char* pPtr = strstr(buffer, "pos=");

                        if (mPtr && pPtr) {
                            char motorNum = *(mPtr + 6);
                            char pVal = *(pPtr + 4);
                            char pCheck = *(pPtr + 6);
                            char* vPtr = pPtr + 4; // Start of value string

                            AccelStepper* targetM = (motorNum == '1') ? &motor1 : &motor2;

                            // 1. Check Keywords (min/max)
                            if (pVal == 'm' && pCheck == 'n') { // min
                                targetM->moveTo(-SAFETY_RUN_LIMIT);
                            } else if (pVal == 'm' && pCheck == 'x') { // max
                                targetM->moveTo(SAFETY_RUN_LIMIT);
                            }
                            // 2. Parse Number for Relative Move
                            else {
                                long steps = 0;
                                bool neg = false;

                                // Check sign
                                if (*vPtr == '-') { neg = true; vPtr++; }
                                else if (*vPtr == '+') { vPtr++; } // Skip explicit +

                                // Parse digits manually to save space (no atoi)
                                while (*vPtr >= '0' && *vPtr <= '9') {
                                    steps = (steps * 10) + (*vPtr - '0');
                                    vPtr++;
                                }

                                if (neg) steps = -steps;
                                if (steps != 0) targetM->move(steps); // Relative move
                                else targetM->stop();
                            }
                            client.print(F("{\"status\":\"ok\"}"));
                        } else {
                            client.print(F("{\"error\":\"bad_req\"}"));
                        }
                    }
                    else {
                        client.print(F("/status\n/set?motor=1&pos=+200\n/set?motor=1&pos=min\n/setip?ip=192.168.1.55\n"));
                    }
                    break;
                }
                if (c == '\n') {
                    currentLineIsBlank = true;
                } else if (c != '\r') {
                    currentLineIsBlank = false;
                }
            }
        }
        delay(1);
        client.stop();
    }
}

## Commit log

2025-12-27 initial version
    [EBSE_VRG131.FCStd, case.FCStd, device.FCStd]
2025-12-27 add endstops
    [Microswitch_SPDT_Vertical.FCStd, device.FCStd]
2026-01-16 add 4th temp sensor
    [device.FCStd, sensor_mount.FCStd]
2026-02-16 add sensor holder
    [sensor_mount2.FCStd]
2026-03-29 fix logic with endstop lock
    [gears-v2.FCStd]
2026-05-10 fix endstop handling for inverted motor and prevent freeze on repeated hits
    - Add direction multiplier constants (M1_DIR/M2_DIR) to generalize endstop
    logic for normal vs inverted motors
    - Use distanceToGo() instead of speed() for direction check — speed can be
    zero during acceleration ramp, causing endstop to be missed
    - Add endstop lock flags to prevent infinite backoff loop when switch stays
    pressed after motor power-off
    - Block encoder input toward a locked endstop
    - Increase BACKOFF_STEPS from 100 to 500 for sufficient mechanical clearance
    [main.cpp]
